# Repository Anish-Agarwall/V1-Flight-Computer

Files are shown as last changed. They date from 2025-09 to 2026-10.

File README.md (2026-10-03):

# V1 Flight Computer

An STM32-based rocket flight computer designed by Anish Agarwal and Aidan Gonzales. This repository contains the KiCad schematics and PCB layout, custom component libraries, and firmware developed in STM32CubeIDE.

The board brings together flight sensing, GPS, LoRa telemetry, microSD logging, main and drogue deployment channels, and a servo output for airbrakes.

## Hardware

The PCB uses four copper layers and an STM32F446RE microcontroller.

| Component | Purpose | Firmware interface |
| --- | --- | --- |
| BMI088 | Accelerometer and gyroscope | I2C1 |
| BMP388 | Pressure, temperature, and barometric altitude | I2C1 |
| LIS3MDL | Magnetometer | I2C1 |
| u-blox NEO-M9N | GPS | USART6 |
| E22-900MM22S | LoRa telemetry | SPI1 |
| W25Q128JVS | 128-Mbit external flash | SPI2 |
| microSD | CSV data logging | SPI3 |

The design also includes battery-voltage and deployment-continuity sensing, a buzzer, a heartbeat LED, and USB-C. The active firmware uses the BMI088; a BMI330 driver is also included in the source tree.

## Firmware

The application is written in C using the STM32 HAL and FatFs. Most of the flight logic is in [`main.c`](V1_STM32/Core/Src/main.c), with separate drivers for the sensors, GPS, radio, SD card, and flash.

The main loop handles:

- Sensor readings and flight-state updates on a nominal 50 ms interval.
- Ground-relative barometric altitude, filtered altitude, and estimated vertical velocity.
- Launch and apogee detection, followed by drogue and main deployment states.
- GPS stream processing and LoRa packet transmission, scheduled at 200 ms intervals.
- Buffered CSV logging to the SD card.
- Servo airbrake control using predicted apogee and a PD controller, enabled seven seconds after launch.

Flight thresholds, deployment settings, and servo limits are defined in `main.c`. The airbrake target and controller gains are inside `Task_Airbrakes()`.

### Data logging

On startup, the firmware selects a numbered log file such as `LOG_0.CSV` or `LOG_1.CSV`. Logged fields include altitude, pressure, temperature, flight state, airbrake output, filtered altitude and velocity, magnetometer readings, and GPS data.

Battery and continuity columns are present, but their periodic sampling task is currently commented out. Data rows also include a Unix timestamp that is missing from the startup CSV header.

The flash driver and a binary logging routine are included, but the current main loop uses the SD logging path and does not call the flash-log flush routine.

## Repository layout

| Path | Contents |
| --- | --- |
| `V1_Hardware/` | KiCad project, schematics, PCB layout, footprints, and 3D models |
| `V1_STM32/` | STM32CubeIDE project and CubeMX configuration |
| `V1_STM32/Core/Src/` | Main application and device drivers |
| `V1_STM32/Core/Inc/` | Headers, telemetry packet definitions, and buffer utilities |
| `V1_STM32/FATFS/` | FatFs configuration and SD disk interface |
| `V1_STM32/Drivers/` | STM32 HAL and CMSIS files |
| `LRA_Parts/` | Component symbols, footprints, and models |

## Opening the project

### Hardware

1. Open `V1_Hardware/V1.kicad_pro` in KiCad. The checked-in design files were saved with KiCad 10.0.
2. In **Preferences → Configure Paths**, set `LRA_PARTS` to the repository's `LRA_Parts` directory.
3. Check the project symbol-library table. Some entries still use absolute Windows paths and need to be pointed to your local copies. Entries that point to a directory should be updated to the corresponding `.kicad_sym` file.

The root schematic is `V1.kicad_sch`. Separate sheets cover power, deployment circuitry, USB-C, memory, GPS/telemetry, and sensors.

### Firmware

1. In STM32CubeIDE, choose **File → Import → General → Existing Projects into Workspace** and select `V1_STM32`.
2. Build the imported project. The repository includes the HAL, CMSIS, and FatFs sources.
3. Use an ST-LINK connection over SWD to program and debug the board. Check the probe settings in the included `V1 Debug.launch` configuration for your setup.

`V1.ioc` contains the CubeMX configuration and records STM32CubeMX 6.14.1 with STM32CubeF4 firmware package V1.28.3. Check the existing application code before regenerating peripheral initialization code.

## Development notes

Some earlier bring-up routines and alternate logging paths remain in the source. Follow the active calls in `main.c` when checking current behavior; a few older comments describe previous pin assignments or hardware revisions.

The `LANDED` state currently follows the main-deployment timer rather than a separate touchdown detector.

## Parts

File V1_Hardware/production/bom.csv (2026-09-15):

Designator | Footprint | Quantity | Value | LCSC Part #
C1, C10, C14, C15, C2, C3, C30, C31, C34, C35, C36, C37, C38, C39, C4, C41, C42, C43, C47, C49, C5, C52, C7, C71, C73, C76 | 0603 | 26 | 100n
C11, C12 | 0603 | 2 | 27p
C13 | 0603 | 1 | 4u7
C17 | 0603 | 1 | 0.47u
C18 | 0805 | 1 | 33u
C28, C40 | 0603 | 2 | 1u
C45, C46, C6, C69, C70, C9 | 0603 | 6 | 10u
C48, C72 | 0603 | 2 | 33n
C50, C51 | 0805 | 2 | 47u
C74, C75 | 0603 | 2 | 22u
C8 | 0603 | 1 | 10n
D1, D2, D4, D7 | 1206 | 4 | RED
J1 | PinHeader_1x04_P2.54mm_Vertical | 1 | Conn_01x04_Pin
J2, J3 | TE_282834-4 | 2 | Screw_Terminal_01x04
J4 | 691210910003 | 1 | Screw_Terminal_01x03
J5, J9 | U.FL_Molex_MCRF_73412-0110_Vertical | 2 | Conn_Coaxial
J7 | 104031-0811 | 1 | 104031-0811
J8 | USB_C_Receptacle_GCT_USB4105-xx-A_16P_TopMnt_Horizontal | 1 | USB_C_Receptacle_USB2.0_16P
L2 | 1210 | 1 | 4.7u
L3 | 1008 | 1 | 27n
L4 | 1008 | 1 | 330n
L6 | 1210 | 1 | 6u8
LS1 | PS1240P02BT | 1 | PS1240P02BT
Q1, Q2 | FDS6681Z | 2 | FDS6681Z
R1, R11, R12, R14, R17, R19, R29, R33, R38, R39, R43, R6, R9 | 0603 | 13 | 10k
R10, R13 | 0603 | 2 | 30k
R15 | 0603 | 1 | 20k
R16 | 0603 | 1 | 2k5
R18, R20 | 0603 | 2 | 100
R2, R30 | 0603 | 2 | 5.1K
R21, R22 | 0603 | 2 | 4k7
R23 | 0603 | 1 | 1k
R25 | 0603 | 1 | 10
R27, R7 | 0603 | 2 | 360k
R28, R8 | 0603 | 2 | 200k
R3, R4 | 0603 | 2 | 75
R34 | 0603 | 1 | 47k
R35 | 0603 | 1 | 15k
R40, R41 | 0603 | 2 | 200
R42 | 0805 | 1 | 90k
R5 | 0603 | 1 | 300
S1, S2 | 500SSP1S1M6QEA | 2 | 500SSP1S1M6QEA
TP1 | TestPoint_Pad_D2.0mm | 1 | 3.3V TestPoint
TP2 | TestPoint_Pad_D2.0mm | 1 | 8V TestPoint
TP3 | TestPoint_Pad_D2.0mm | 1 | VBUS TestPoint
TP4 | TestPoint_Pad_D2.0mm | 1 | GND TestPoint
U1 | LQFP-64_10x10mm_P0.5mm | 1 | STM32F446RETx
U10 | ublox_NEO | 1 | NEO-M9N
U12 | BMP388 | 1 | BMP388
U13, U3 | TPS62933DRLR | 2 | TPS62933DRLR
U15 | LM3940IMPX-3.3_NOPB | 1 | LM3940IMPX-3.3_NOPB
U16 | LGA-12_2x2mm_P0.5mm | 1 | LIS3MDL
U17, U9 | IRLML6346TRPBF | 2 | IRLML6346TRPBF | IRLML6346TRPBF
U2 | SOIC-8_5.3x5.3mm_P1.27mm | 1 | W25Q128JVS
U4 | E22-900MM22S | 1 | E22-900MM22S
U5 | BMI330 | 1 | BMI330
U6 | TPD1E0B04DPYT | 1 | TPD1E0B04DPYT
U7 | TPD4E05U06DQAR | 1 | TPD4E05U06DQAR
Y2 | ABLS-8.000MHZ-B2-T | 1 | ABLS-8.000MHZ-B2-T

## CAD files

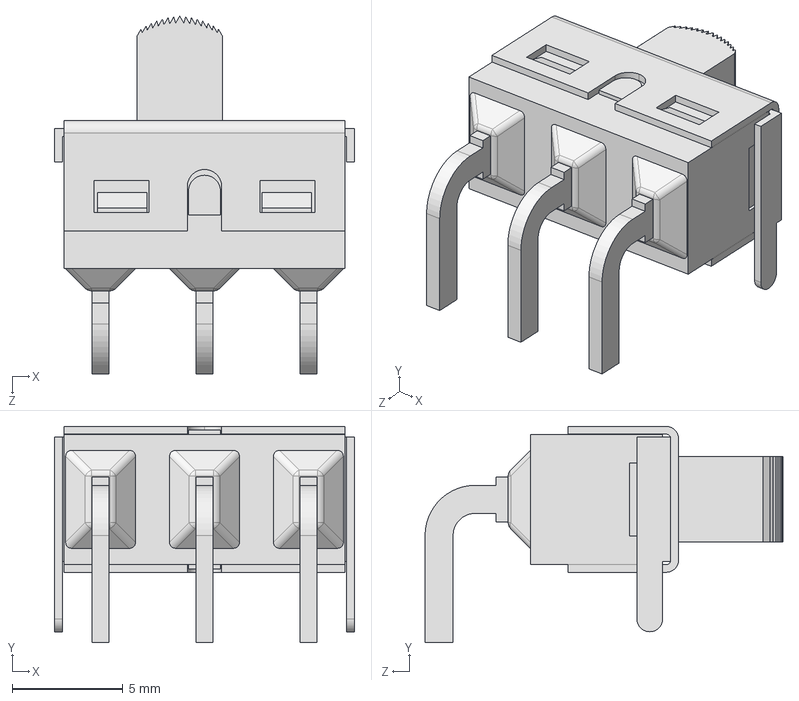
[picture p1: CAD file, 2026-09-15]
LRA_Parts/500SSP1S1M6QEA/500SSP1S1M6QEA.step
13.6 x 9.78 x 16.2 mm

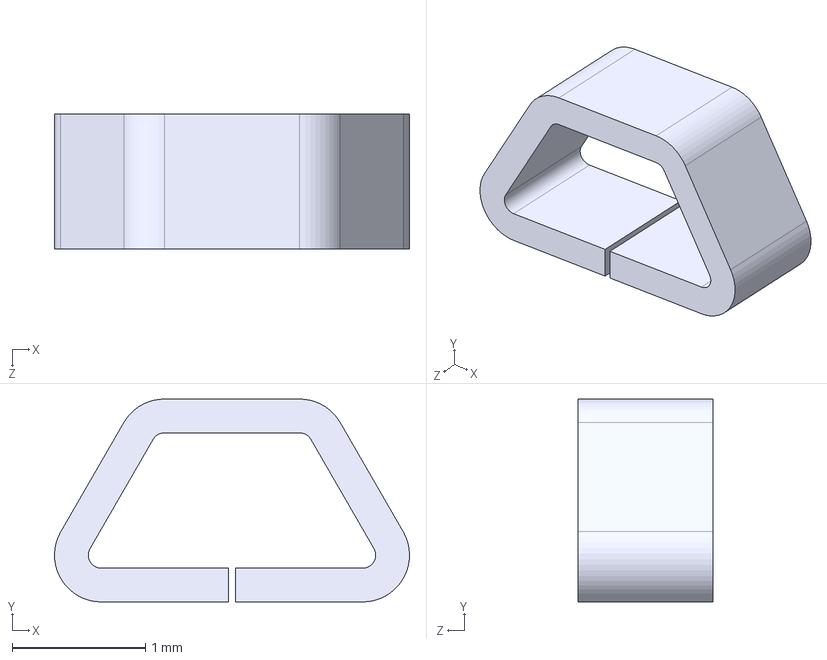
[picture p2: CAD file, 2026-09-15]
LRA_Parts/5015/5015.step
2.67 x 1.52 x 1.02 mm

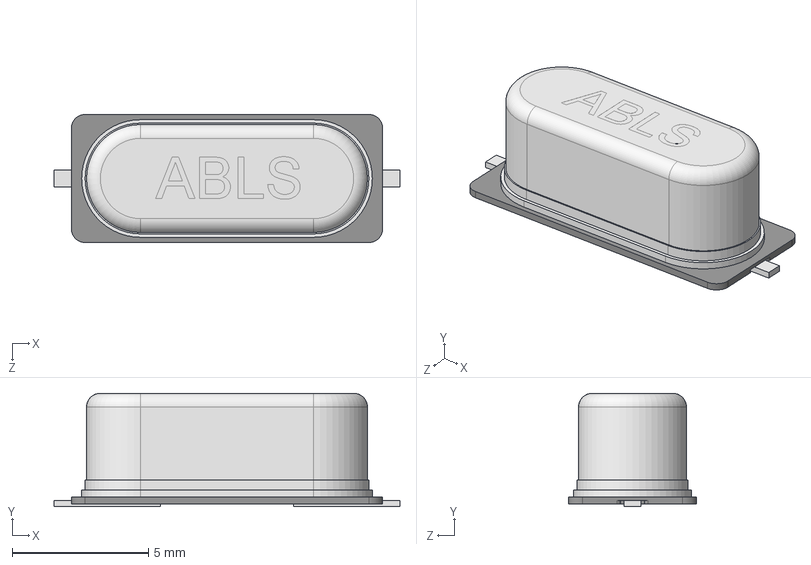
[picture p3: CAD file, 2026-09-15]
LRA_Parts/ABLS-8.000MHZ-B2-T/ABLS-8.000MHZ-B2-T.step
12.7 x 4.17 x 4.70 mm

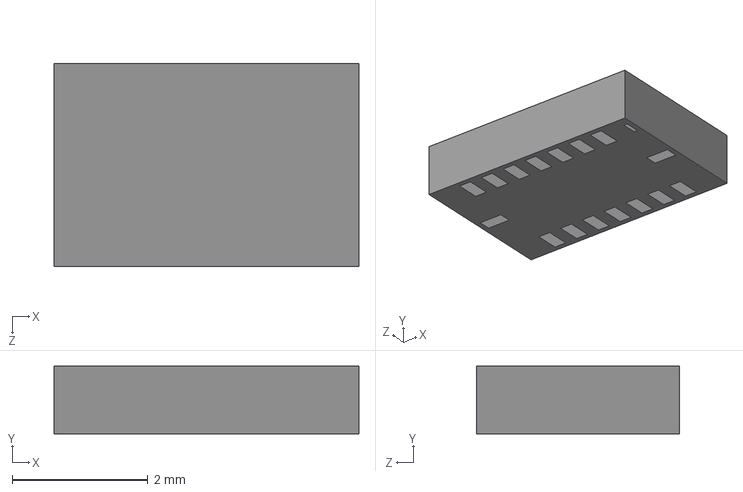
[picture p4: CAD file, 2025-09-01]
LRA_Parts/BMI088/BMI088.step
4.50 x 1.00 x 3.00 mm

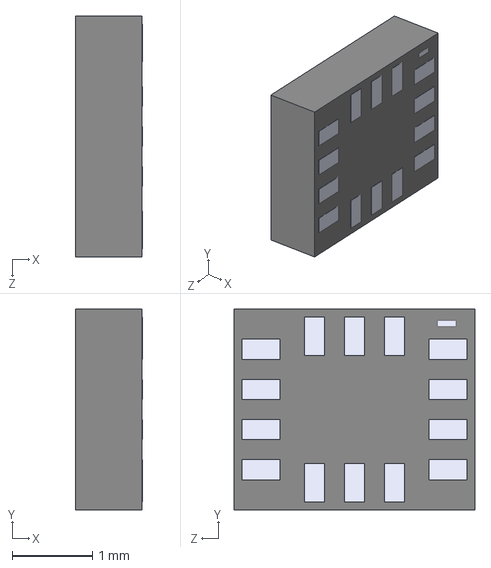
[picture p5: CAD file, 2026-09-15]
LRA_Parts/BMI330/BMI330.stp
0.837 x 2.50 x 3.00 mm

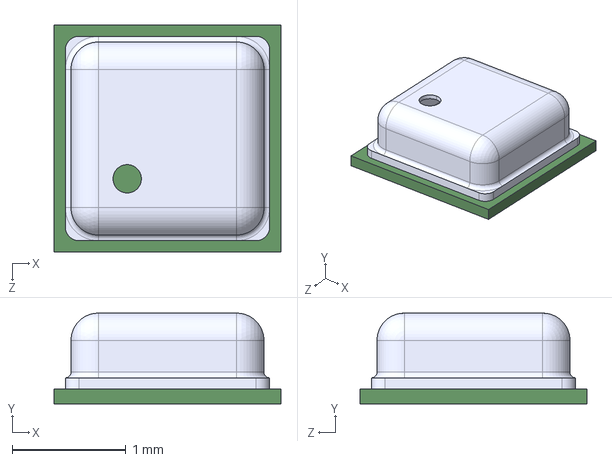
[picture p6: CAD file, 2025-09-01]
LRA_Parts/BMP388/BMP388.step
2.00 x 0.8 x 2.00 mm

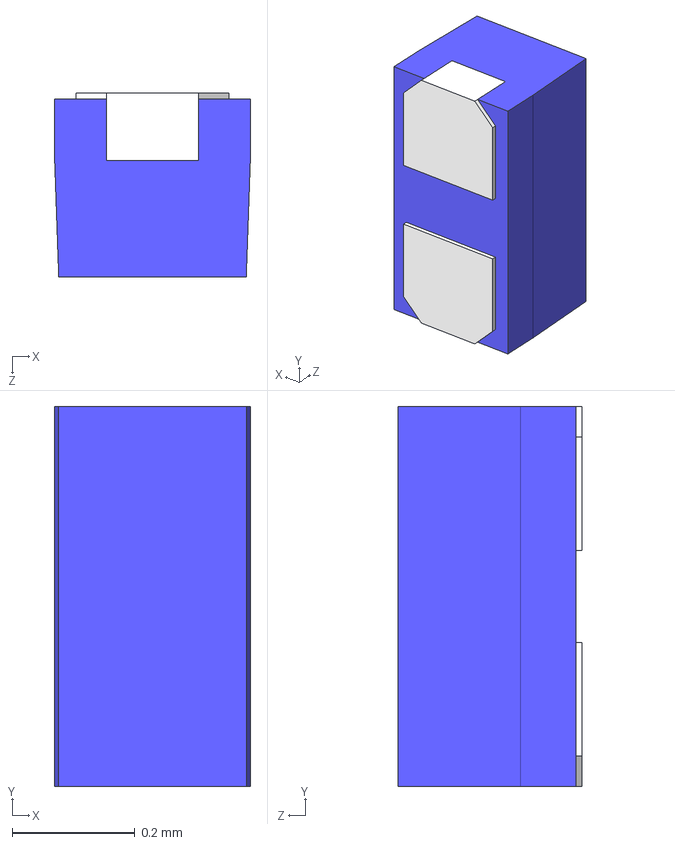
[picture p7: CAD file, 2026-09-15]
LRA_Parts/DF2B6M4SL_L3F/DF2B6M4BSL,L3F.step
0.32 x 0.62 x 0.3 mm

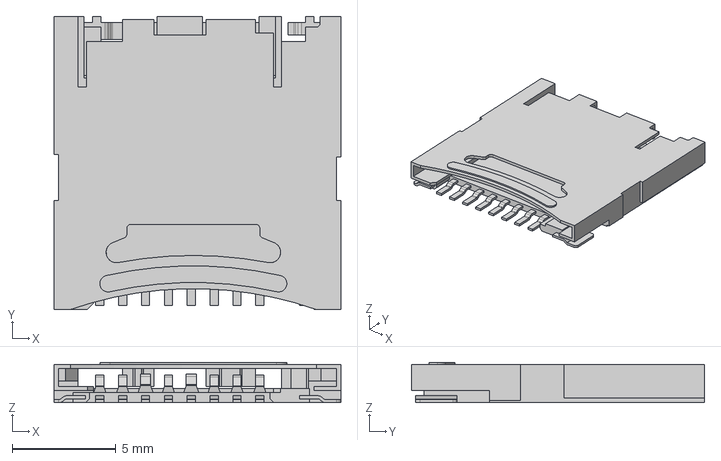
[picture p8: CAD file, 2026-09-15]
LRA_Parts/DM3CS-SF/DM3CS-SF.step
13.8 x 14.1 x 1.93 mm

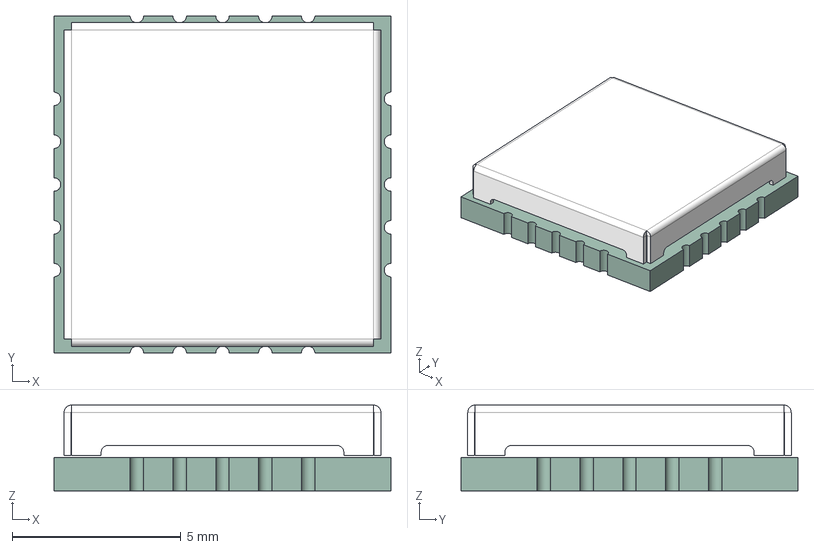
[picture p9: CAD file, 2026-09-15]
LRA_Parts/E22-900MM22S/E07-900MM10S.step
10.0 x 10.0 x 2.55 mm
PBZ-135
10705-V1.1_PCB

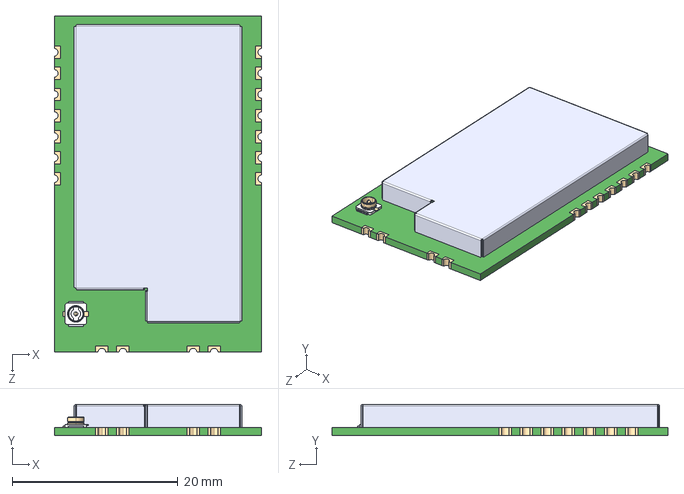
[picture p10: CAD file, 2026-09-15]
LRA_Parts/E22-900T30S/E22-900T30S.step
25.0 x 3.77 x 40.5 mm

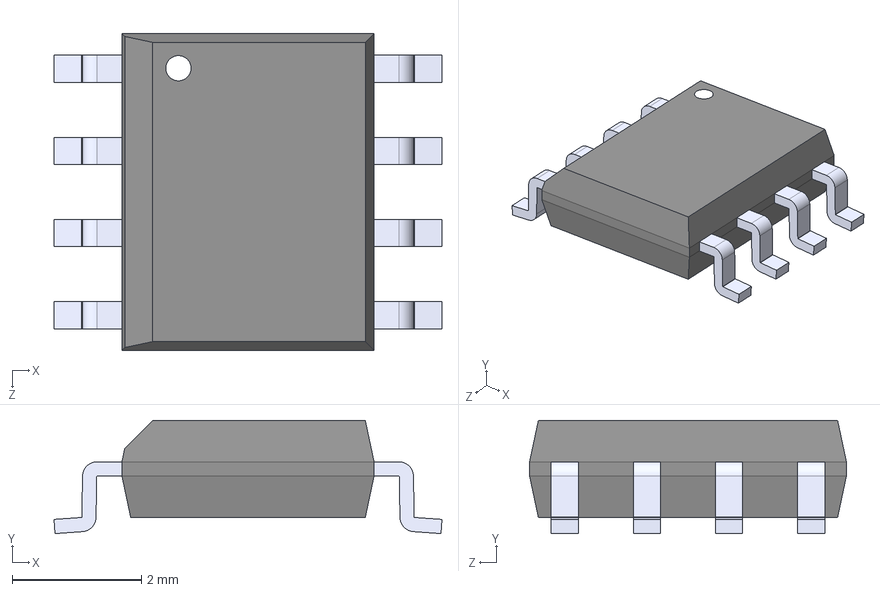
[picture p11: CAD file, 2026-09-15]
LRA_Parts/FDS6681Z/FDS6681Z.step
6.00 x 1.75 x 4.90 mm

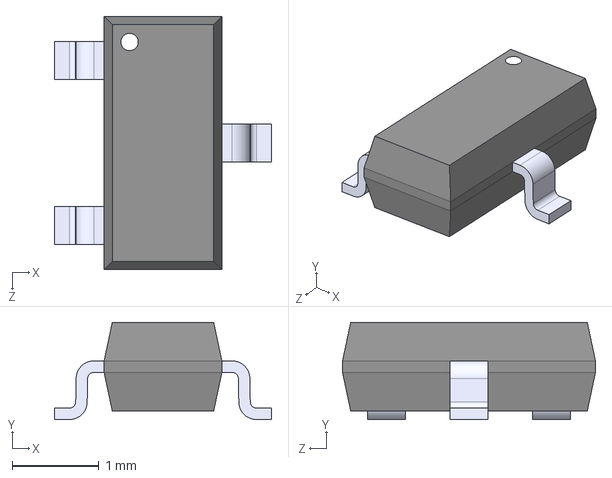
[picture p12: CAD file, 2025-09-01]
LRA_Parts/IRLML6344TRPBF/IRLML6344TRPBF.step
2.51 x 1.12 x 2.92 mm

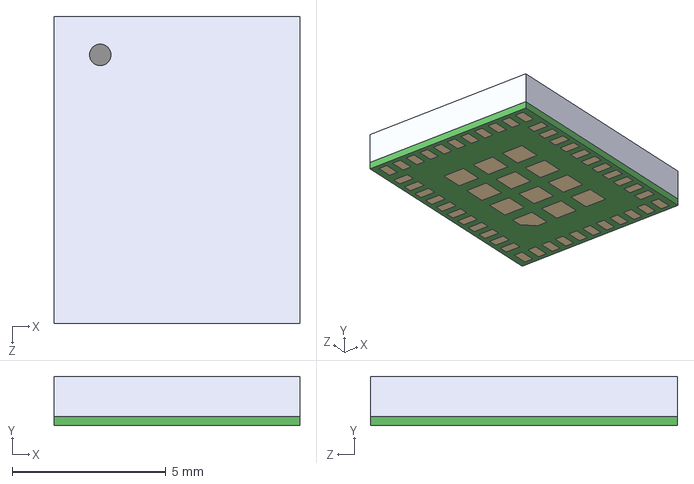
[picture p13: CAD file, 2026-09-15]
LRA_Parts/LBAA0QB1SJ-296/LBAA0QB1SJ-296.step
8.00 x 1.60 x 10.0 mm

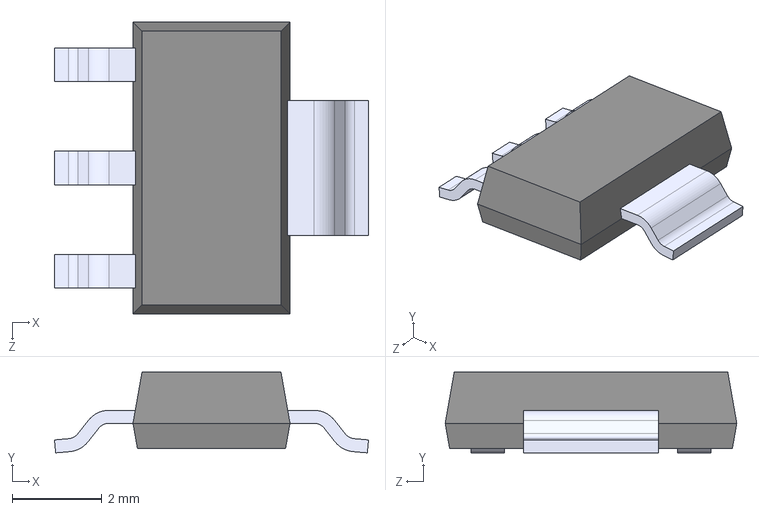
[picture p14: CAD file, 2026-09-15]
LRA_Parts/LM3940IMPX_3_3_NOPB/LM3940IMPX-3.3_NOPB.step
7.00 x 1.80 x 6.50 mm

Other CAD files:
LRA_Parts/IRLML6346TRPBF/IRLML6346TRPBF.step
LRA_Parts/LTST_C171KRKT/LED_LTST-C171_LTO.step
LRA_Parts/NEO-M9N-00B/NEO-M9N-00B.STEP
LRA_Parts/PS1240P02BT/PS1240P02BT.step
LRA_Parts/104031-0811/104031-0811.step
LRA_Parts/282834_4/282834-4.step
LRA_Parts/389690003/389690003.stp
LRA_Parts/389690004/389690004.step
LRA_Parts/691137710003/691137710003.stp
LRA_Parts/691210910003/691210910003.stp
LRA_Parts/TE_282834-4/TE_282834-4.STEP
LRA_Parts/TPD1E0B04DPYT/TPD1E0B04DPYT.step
LRA_Parts/TPD2E001DRSR/TPD2E001DRSR.step
LRA_Parts/TPD2E001DRYR/TPD2E001DRYR.step
LRA_Parts/TPD2E001DZDR/TPD2E001DZDR.step
LRA_Parts/TPD4E05U06DQAR/TPD4E05U06DQAR.step
LRA_Parts/TPS62933DRLR/TPS62933DRLR.step
LRA_Parts/USB4215-03-A_REVA/usb4215-03-a.stp
LRA_Parts/molex_2x1/1053091102.stp
LRA_Parts/molex_3x1/1053091103.stp
LRA_Parts/molex_4x1/1053091104.stp
LRA_Parts/ul_MP2393GTL-Z (1)/SOT583_MP2393.step
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

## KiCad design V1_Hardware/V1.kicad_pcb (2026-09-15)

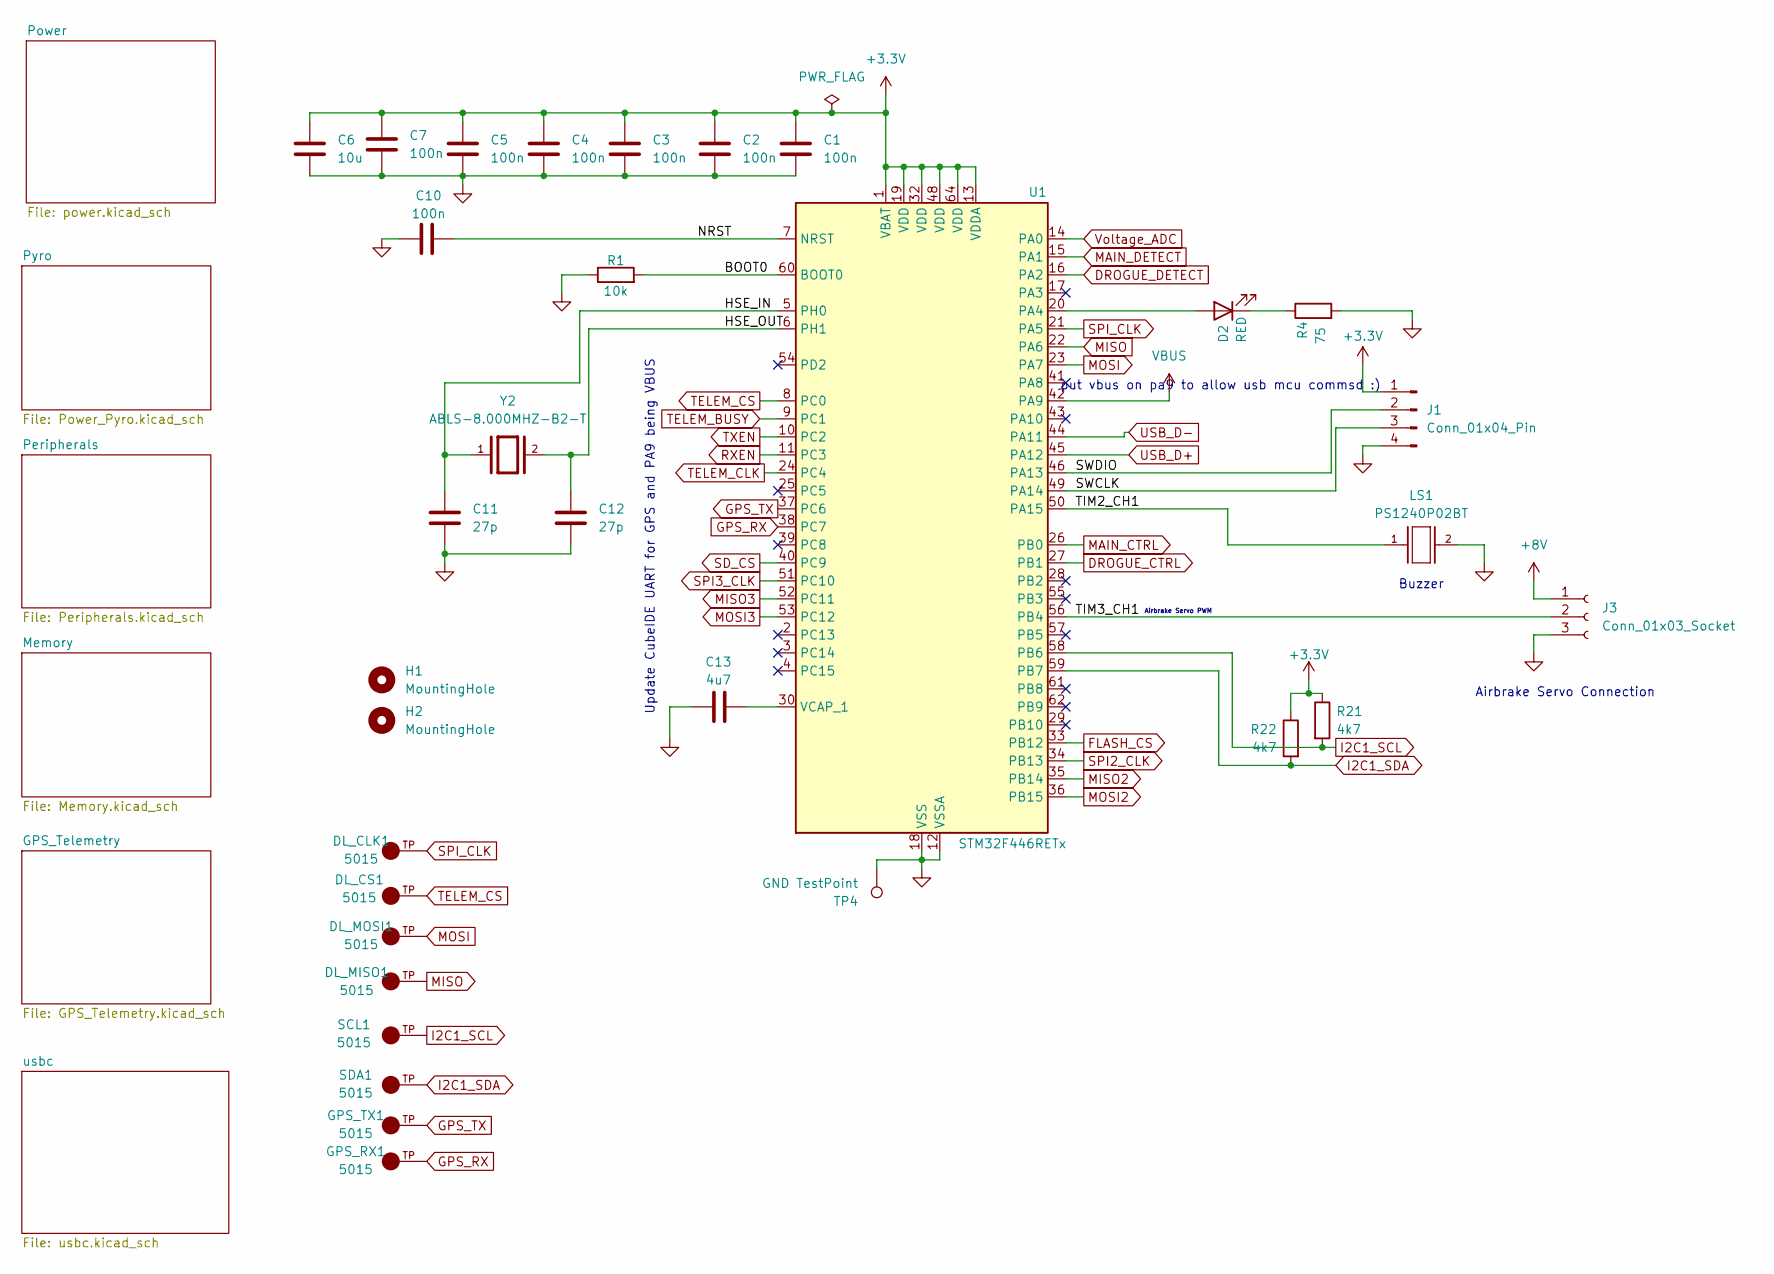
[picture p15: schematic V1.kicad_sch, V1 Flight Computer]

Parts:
C1, C2, C3, C4, C5, C7, C10: 100n; C_0603_1608Metric_Pad1.08x0.95mm_HandSolder
C6: 10u; C_0603_1608Metric_Pad1.08x0.95mm_HandSolder
C11, C12: 27p; C_0603_1608Metric_Pad1.08x0.95mm_HandSolder
C13: 4u7; C_0603_1608Metric_Pad1.08x0.95mm_HandSolder
D2: RED; LED_1206_3216Metric_Pad1.42x1.75mm_HandSolder
DL_CLK1: 5015; PARTREV F
DL_CS1: 5015; PARTREV F
DL_MISO1: 5015; PARTREV F
DL_MOSI1: 5015; PARTREV F
GPS_RX1: 5015; PARTREV F
GPS_TX1: 5015; PARTREV F
H1, H2: MountingHole; MountingHole_3.2mm_M3
J1: Conn_01x04_Pin; PinHeader_1x04_P2.54mm_Vertical
J3: Conn_01x03_Socket; Molex_Nano-Fit_105309-xx03_1x03_P2.50mm_Vertical
LS1: PS1240P02BT
R1: 10k; R_0603_1608Metric_Pad0.98x0.95mm_HandSolder
R4: 75; R_0603_1608Metric_Pad0.98x0.95mm_HandSolder
R21, R22: 4k7; R_0603_1608Metric_Pad0.98x0.95mm_HandSolder
SCL1: 5015; PARTREV F
SDA1: 5015; PARTREV F
TP4: GND TestPoint; TestPoint_Pad_D2.0mm
U1: STM32F446RETx; LQFP-64_10x10mm_P0.5mm
Y2: ABLS-8.000MHZ-B2-T; PARTREV 02.16.2021

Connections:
+3.3V: C1.1, C2.1, C3.1, C4.1, C5.1, C6.1, C7.1, J1.1, R21.1, R22.1, U1.1 (VBAT), U1.13 (VDDA), U1.19 (VDD), U1.32 (VDD), U1.48 (VDD), U1.64 (VDD); also elsewhere on the board
+8V: J3.1; also elsewhere on the board
/BOOT0: R1.2, U1.60 (BOOT0)
/HSE_IN: C11.1, U1.5 (PH0), Y2.1
/HSE_OUT: C12.1, U1.6 (PH1), Y2.2
/NRST: C10.2, U1.7 (NRST)
/SWCLK: J1.3, U1.49 (PA14)
/SWDIO: J1.2, U1.46 (PA13)
/TIM2_CH1: LS1.1, U1.50 (PA15)
/TIM3_CH1: J3.2, U1.56 (PB4)
DROGUE_CTRL: U1.27 (PB1); also elsewhere on the board
DROGUE_DETECT: U1.16 (PA2); also elsewhere on the board
FLASH_CS: U1.33 (PB12); also elsewhere on the board
GND: C1.2, C2.2, C3.2, C4.2, C5.2, C6.2, C7.2, C10.1, C11.2, C12.2, C13.1, J1.4, J3.3, LS1.2, R1.1, R4.2, TP4.1 (1_1), U1.12 (VSSA), U1.18 (VSS), U1.31 (VSS), U1.47 (VSS), U1.63 (VSS); also elsewhere on the board
GPS_RX: GPS_RX1.TP, U1.38 (PC7); also elsewhere on the board
GPS_TX: GPS_TX1.TP, U1.37 (PC6); also elsewhere on the board
I2C1_SCL: R21.2, SCL1.TP, U1.58 (PB6); also elsewhere on the board
I2C1_SDA: R22.2, SDA1.TP, U1.59 (PB7); also elsewhere on the board
MAIN_CTRL: U1.26 (PB0); also elsewhere on the board
MAIN_DETECT: U1.15 (PA1); also elsewhere on the board
MISO: DL_MISO1.TP, U1.22 (PA6); also elsewhere on the board
MISO2: U1.35 (PB14); also elsewhere on the board
MISO3: U1.52 (PC11); also elsewhere on the board
MOSI: DL_MOSI1.TP, U1.23 (PA7); also elsewhere on the board
MOSI2: U1.36 (PB15); also elsewhere on the board
MOSI3: U1.53 (PC12); also elsewhere on the board
unnamed: D2.2 (A), U1.20 (PA4)
unnamed: D2.1 (K), R4.1
unnamed: C13.2, U1.30 (VCAP_1)
RXEN: U1.11 (PC3); also elsewhere on the board
SD_CS: U1.40 (PC9); also elsewhere on the board
SPI2_CLK: U1.34 (PB13); also elsewhere on the board
SPI3_CLK: U1.51 (PC10); also elsewhere on the board
SPI_CLK: DL_CLK1.TP, U1.21 (PA5); also elsewhere on the board
TELEM_BUSY: U1.9 (PC1); also elsewhere on the board
TELEM_CLK: U1.24 (PC4); also elsewhere on the board
TELEM_CS: DL_CS1.TP, U1.8 (PC0); also elsewhere on the board
TXEN: U1.10 (PC2); also elsewhere on the board
USB_D+: U1.45 (PA12); also elsewhere on the board
USB_D-: U1.44 (PA11); also elsewhere on the board
VBUS: U1.42 (PA9); also elsewhere on the board
Voltage_ADC: U1.14 (PA0); also elsewhere on the board

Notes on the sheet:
Update CubeIDE UART for GPS and PA9 being VBUS
put vbus on pa9 to allow usb mcu commsd :)
Airbrake Servo Connection
Airbrake Servo PWM
Buzzer

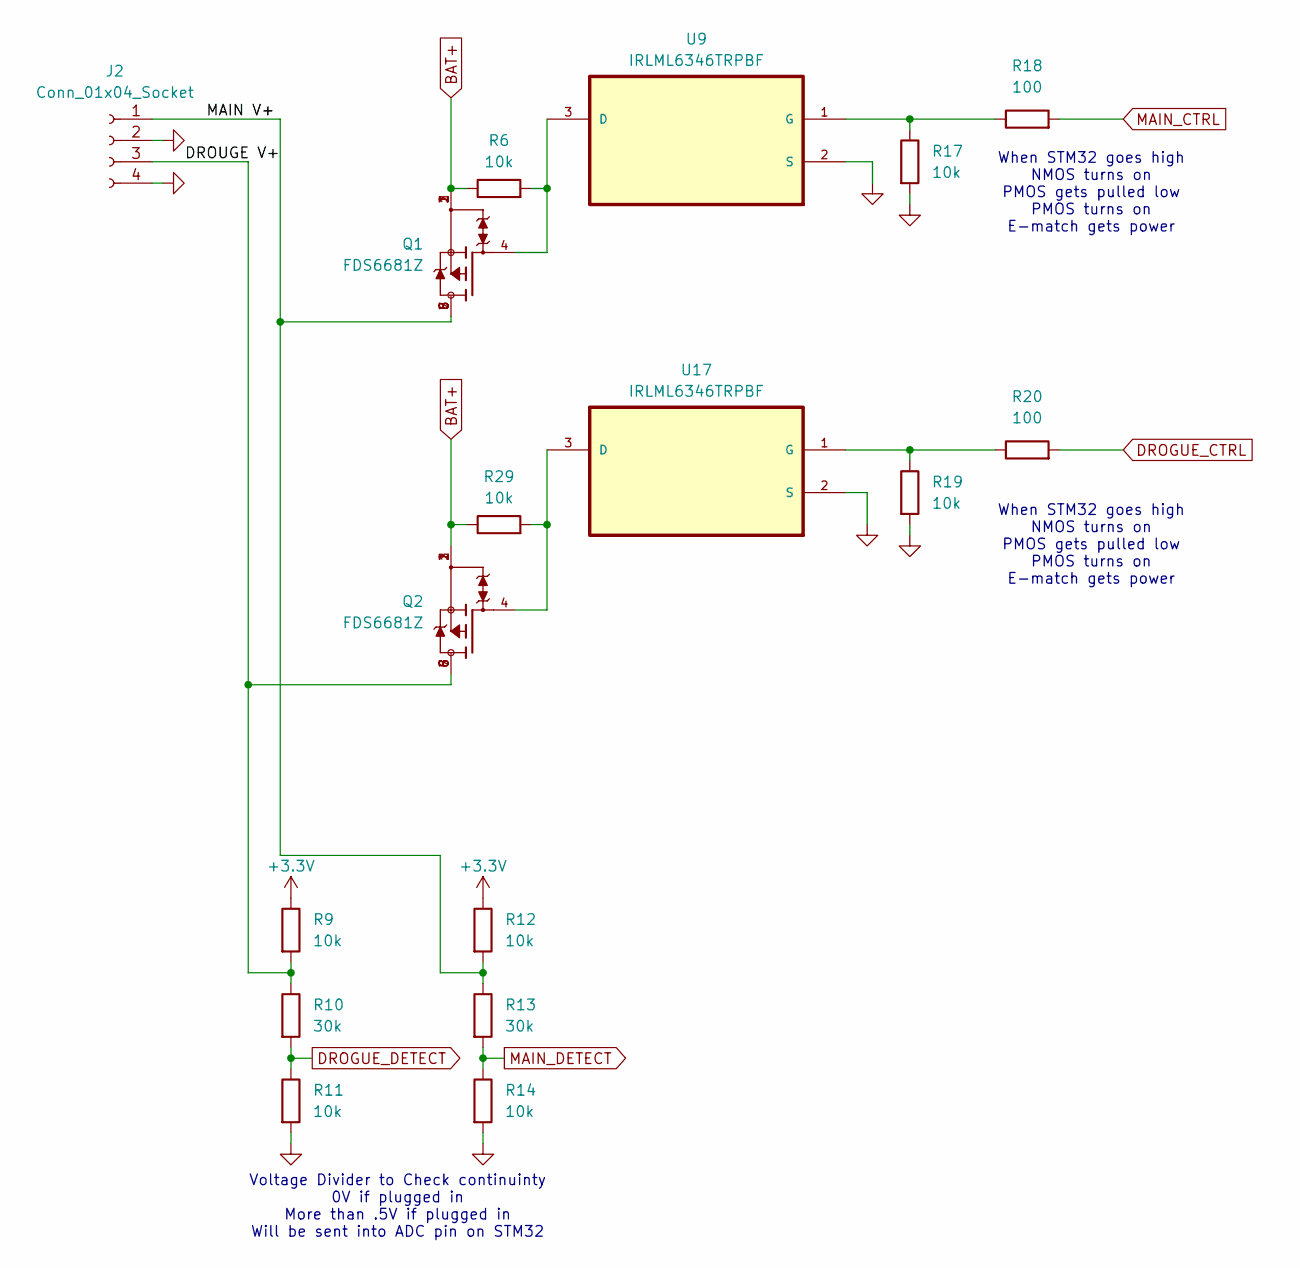
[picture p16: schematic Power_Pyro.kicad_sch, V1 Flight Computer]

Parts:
J2: Conn_01x04_Socket; Molex_Nano-Fit_105309-xx04_1x04_P2.50mm_Vertical
Q1, Q2: FDS6681Z
R6, R9, R11, R12, R14, R17, R19, R29: 10k; R_0603_1608Metric_Pad0.98x0.95mm_HandSolder
R10, R13: 30k; R_0603_1608Metric_Pad0.98x0.95mm_HandSolder
R18, R20: 100; R_0603_1608Metric_Pad0.98x0.95mm_HandSolder
U9, U17: IRLML6346TRPBF; MPN IRLML6346TRPBF

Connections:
+3.3V: R9.1, R12.1; also elsewhere on the board
/Pyro/DROUGE V+: J2.3, Q2.5, Q2.6, Q2.7, Q2.8, R9.2, R10.1
/Pyro/MAIN V+: J2.1, Q1.5, Q1.6, Q1.7, Q1.8, R12.2, R13.1
BAT+: Q1.1, Q1.2, Q1.3, Q2.1, Q2.2, Q2.3, R6.1, R29.1; also elsewhere on the board
DROGUE_CTRL: R20.2; also elsewhere on the board
DROGUE_DETECT: R10.2, R11.1; also elsewhere on the board
GND: J2.2, J2.4, R11.2, R14.2, R17.2, R19.2, U9.2 (S), U17.2 (S); also elsewhere on the board
MAIN_CTRL: R18.2; also elsewhere on the board
MAIN_DETECT: R13.2, R14.1; also elsewhere on the board
unnamed: Q1.4, R6.2, U9.3 (D)
unnamed: R17.1, R18.1, U9.1 (G)
unnamed: Q2.4, R29.2, U17.3 (D)
unnamed: R19.1, R20.1, U17.1 (G)

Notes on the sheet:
Voltage Divider to Check continuinty 0V if plugged in More than .5V if plugged in Will be sent into ADC pin on STM32
When STM32 goes high NMOS turns on PMOS gets pulled low PMOS turns on E-match gets power

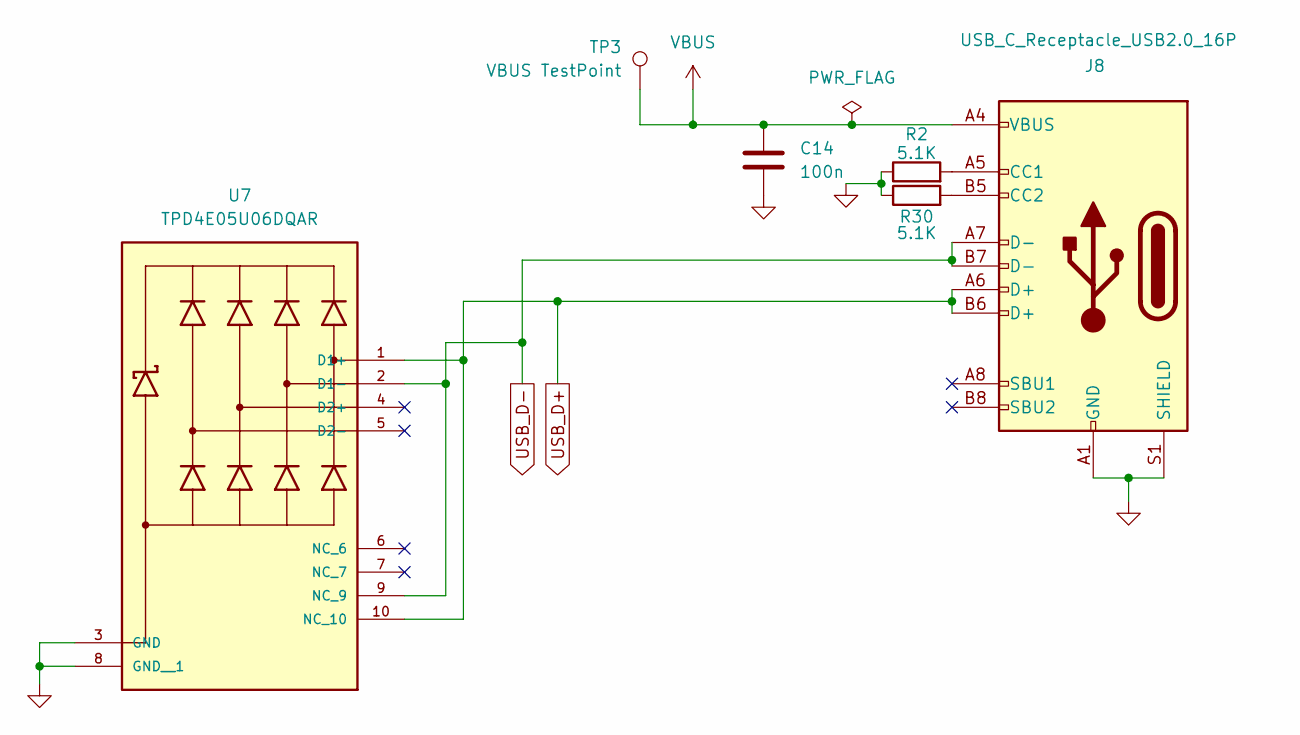
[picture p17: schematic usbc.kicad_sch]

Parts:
C14: 100n; C_0603_1608Metric_Pad1.08x0.95mm_HandSolder
J8: USB_C_Receptacle_USB2.0_16P; USB_C_Receptacle_GCT_USB4105-xx-A_16P_TopMnt_Horizontal
R2, R30: 5.1K; R_0603_1608Metric_Pad0.98x0.95mm_HandSolder
TP3: VBUS TestPoint; TestPoint_Pad_D2.0mm
U7: TPD4E05U06DQAR; PARTREV N

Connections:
GND: C14.1, J8.A1 (GND), J8.A12 (GND), J8.B1 (GND), J8.B12 (GND), J8.S1 (SHIELD), R2.1, R30.1, U7.3 (GND), U7.8 (GND__1); also elsewhere on the board
unnamed: J8.A5 (CC1), R2.2
unnamed: J8.B5 (CC2), R30.2
USB_D+: J8.A6 (D+), J8.B6 (D+), U7.1 (D1+), U7.10 (NC_10); also elsewhere on the board
USB_D-: J8.A7 (D-), J8.B7 (D-), U7.2 (D1-), U7.9 (NC_9); also elsewhere on the board
VBUS: C14.2, J8.A4 (VBUS), J8.A9 (VBUS), J8.B4 (VBUS), J8.B9 (VBUS), TP3.1 (1_1); also elsewhere on the board

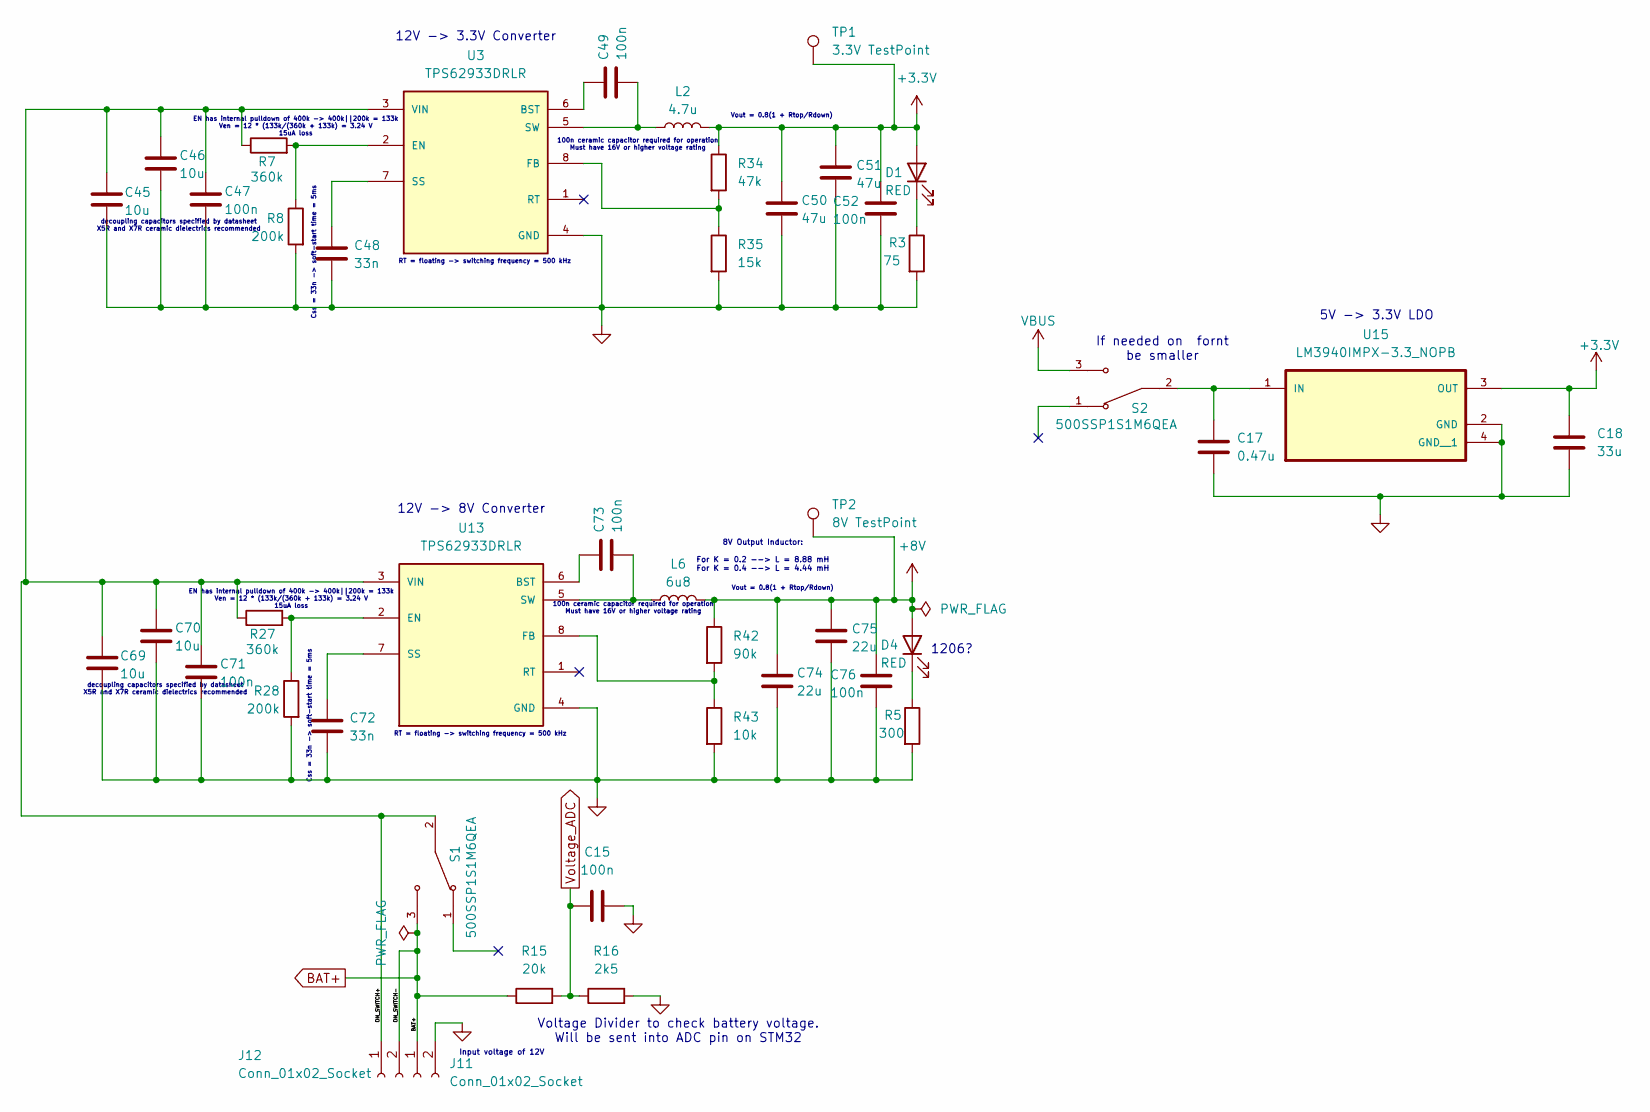
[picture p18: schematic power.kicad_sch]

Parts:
C15, C47, C49, C52, C71, C73, C76: 100n; C_0603_1608Metric_Pad1.08x0.95mm_HandSolder
C17: 0.47u; C_0603_1608Metric_Pad1.08x0.95mm_HandSolder
C18: 33u; C_0805_2012Metric_Pad1.18x1.45mm_HandSolder
C45, C46, C69, C70: 10u; C_0603_1608Metric_Pad1.08x0.95mm_HandSolder
C48, C72: 33n; C_0603_1608Metric_Pad1.08x0.95mm_HandSolder
C50, C51: 47u; C_0805_2012Metric_Pad1.18x1.45mm_HandSolder
C74, C75: 22u; C_0603_1608Metric_Pad1.08x0.95mm_HandSolder
D1, D4: RED; LED_1206_3216Metric_Pad1.42x1.75mm_HandSolder
J11, J12: Conn_01x02_Socket; Molex_Nano-Fit_105309-xx02_1x02_P2.50mm_Vertical
L2: 4.7u; L_1210_3225Metric_Pad1.42x2.65mm_HandSolder
L6: 6u8; L_1210_3225Metric_Pad1.42x2.65mm_HandSolder
R3: 75; R_0603_1608Metric_Pad0.98x0.95mm_HandSolder
R5: 300; R_0603_1608Metric_Pad0.98x0.95mm_HandSolder
R7, R27: 360k; R_0603_1608Metric_Pad0.98x0.95mm_HandSolder
R8, R28: 200k; R_0603_1608Metric_Pad0.98x0.95mm_HandSolder
R15: 20k; R_0603_1608Metric_Pad0.98x0.95mm_HandSolder
R16: 2k5; R_0603_1608Metric_Pad0.98x0.95mm_HandSolder
R34: 47k; R_0603_1608Metric_Pad0.98x0.95mm_HandSolder
R35: 15k; R_0603_1608Metric_Pad0.98x0.95mm_HandSolder
R42: 90k; R_0805_2012Metric_Pad1.20x1.40mm_HandSolder
R43: 10k; R_0603_1608Metric_Pad0.98x0.95mm_HandSolder
S1, S2: 500SSP1S1M6QEA; PARTREV D
TP1: 3.3V TestPoint; TestPoint_Pad_D2.0mm
TP2: 8V TestPoint; TestPoint_Pad_D2.0mm
U3, U13: TPS62933DRLR; PARTREV D
U15: LM3940IMPX-3.3_NOPB

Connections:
+3.3V: C18.1, C50.1, C51.1, C52.1, D1.2 (A), L2.2, R34.1, TP1.1 (1_1), U15.3 (OUT); also elsewhere on the board
+8V: C74.1, C75.1, C76.1, D4.2 (A), L6.2, R42.1, TP2.1 (1_1); also elsewhere on the board
/Power/ON_SWITCH+: C45.1, C46.1, C47.1, C69.1, C70.1, C71.1, J12.1, R7.1, R27.1, S1.2, U3.3 (VIN), U13.3 (VIN)
BAT+: J11.1, J12.2, R15.1, S1.3; also elsewhere on the board
GND: C15.2, C17.2, C18.2, C45.2, C46.2, C47.2, C48.2, C50.2, C51.2, C52.2, C69.2, C70.2, C71.2, C72.2, C74.2, C75.2, C76.2, J11.2, R3.2, R5.2, R8.2, R16.2, R28.2, R35.2, R43.2, U3.4 (GND), U13.4 (GND), U15.2 (GND), U15.4 (GND__1); also elsewhere on the board
unnamed: D1.1 (K), R3.1
unnamed: D4.1 (K), R5.1
unnamed: C49.1, U3.6 (BST)
unnamed: R7.2, R8.1, U3.2 (EN)
unnamed: R34.2, R35.1, U3.8 (FB)
unnamed: C48.1, U3.7 (SS)
unnamed: C49.2, L2.1, U3.5 (SW)
unnamed: C73.1, U13.6 (BST)
unnamed: R27.2, R28.1, U13.2 (EN)
unnamed: R42.2, R43.1, U13.8 (FB)
unnamed: C72.1, U13.7 (SS)
unnamed: C73.2, L6.1, U13.5 (SW)
unnamed: C17.1, S2.2, U15.1 (IN)
VBUS: S2.3; also elsewhere on the board
Voltage_ADC: C15.1, R15.2, R16.1; also elsewhere on the board

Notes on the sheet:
8V Output Inductor: For K = 0.2 --> L = 8.88 mH For K = 0.4 --> L = 4.44 mH
12V -> 8V Converter
Vout = 0.8(1 + Rtop/Rdown)
Voltage Divider to check battery voltage. Will be sent into ADC pin on STM32
100n ceramic capacitor required for operation Must have 16V or higher voltage rating
Css = 33n -> soft-start time = 5ms
EN has internal pulldown of 400k -> 400k||200k = 133k Ven = 12 * (133k/(360k + 133k) = 3.24 V 15uA loss
RT = floating -> switching frequency = 500 kHz
5V -> 3.3V LDO
Input voltage of 12V
1206?
12V -> 3.3V Converter
decoupling capacitors specified by datasheet X5R and X7R ceramic dielectrics recommended
If needed on fornt be smaller

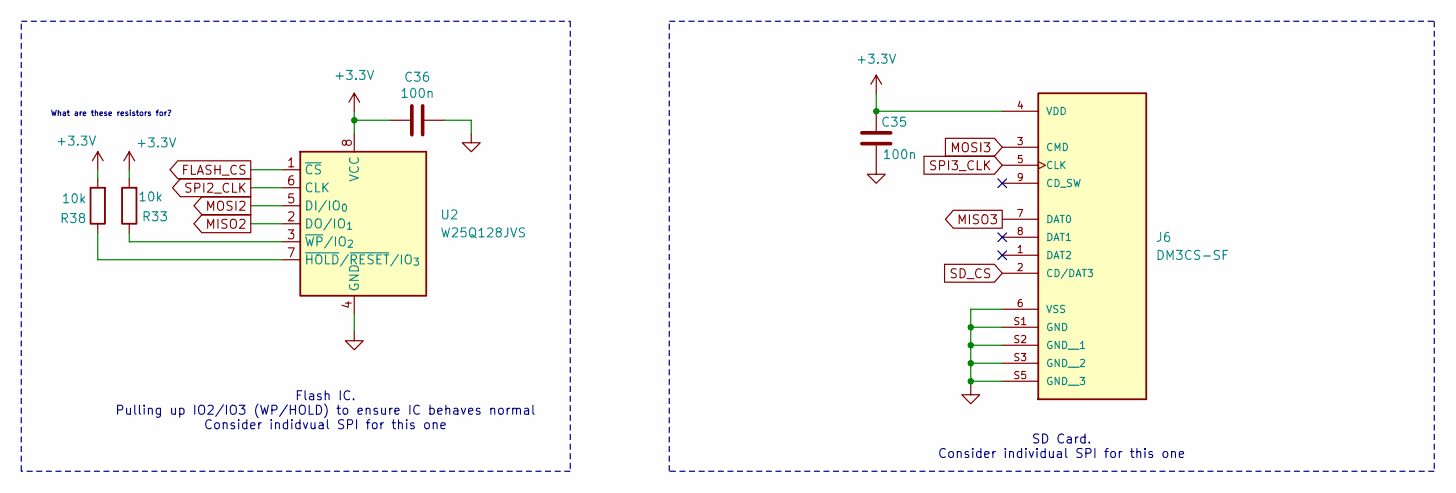
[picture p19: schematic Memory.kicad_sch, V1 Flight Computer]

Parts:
C35, C36: 100n; C_0603_1608Metric_Pad1.08x0.95mm_HandSolder
J6: DM3CS-SF; PARTREV n/a
R33, R38: 10k; R_0603_1608Metric_Pad0.98x0.95mm_HandSolder
U2: W25Q128JVS; SOIC-8_5.3x5.3mm_P1.27mm

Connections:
+3.3V: C35.2, C36.1, J6.4 (VDD), R33.2, R38.2, U2.8 (VCC); also elsewhere on the board
FLASH_CS: U2.1 (~CS); also elsewhere on the board
GND: C35.1, C36.2, J6.6 (VSS), J6.S1 (GND), J6.S2 (GND__1), J6.S3 (GND__2), J6.S5 (GND__3), U2.4 (GND); also elsewhere on the board
MISO2: U2.2 (DO/IO_{1}); also elsewhere on the board
MISO3: J6.7 (DAT0); also elsewhere on the board
MOSI2: U2.5 (DI/IO_{0}); also elsewhere on the board
MOSI3: J6.3 (CMD); also elsewhere on the board
unnamed: R38.1, U2.7 (~HOLD/~RESET/IO_{3})
unnamed: R33.1, U2.3 (~WP/IO_{2})
SD_CS: J6.2 (CD/DAT3); also elsewhere on the board
SPI2_CLK: U2.6 (CLK); also elsewhere on the board
SPI3_CLK: J6.5 (CLK); also elsewhere on the board

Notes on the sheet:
Flash IC. Pulling up IO2/IO3 (WP/HOLD) to ensure IC behaves normal Consider indidvual SPI for this one
SD Card. Consider individual SPI for this one
What are these resistors for?

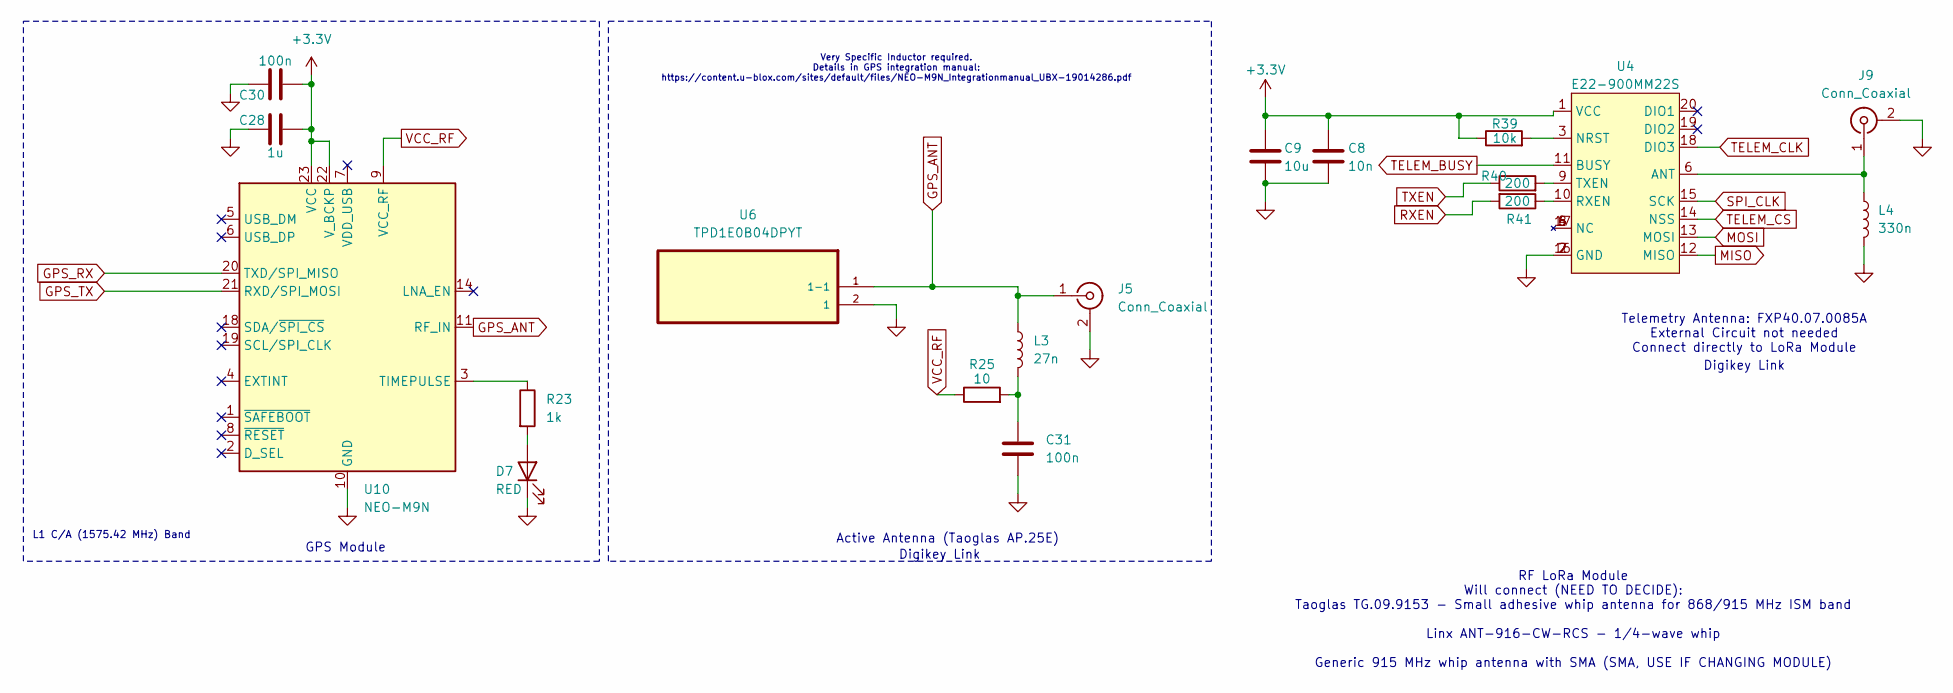
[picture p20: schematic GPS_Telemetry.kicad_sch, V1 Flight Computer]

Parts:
C8: 10n; C_0603_1608Metric_Pad1.08x0.95mm_HandSolder
C9: 10u; C_0603_1608Metric_Pad1.08x0.95mm_HandSolder
C28: 1u; C_0603_1608Metric_Pad1.08x0.95mm_HandSolder
C30, C31: 100n; C_0603_1608Metric_Pad1.08x0.95mm_HandSolder
D7: RED; LED_1206_3216Metric_Pad1.42x1.75mm_HandSolder
J5, J9: Conn_Coaxial; U.FL_Molex_MCRF_73412-0110_Vertical
L3: 27n; L_1008_2520Metric_Pad1.43x2.20mm_HandSolder
L4: 330n; L_1008_2520Metric_Pad1.43x2.20mm_HandSolder
R23: 1k; R_0603_1608Metric_Pad0.98x0.95mm_HandSolder
R25: 10; R_0603_1608Metric_Pad0.98x0.95mm_HandSolder
R39: 10k; R_0603_1608Metric_Pad0.98x0.95mm_HandSolder
R40, R41: 200; R_0603_1608Metric_Pad0.98x0.95mm_HandSolder
U4: E22-900MM22S
U6: TPD1E0B04DPYT
U10: NEO-M9N; ublox_NEO

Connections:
+3.3V: C8.1, C9.1, C28.2, C30.2, R39.1, U4.1 (VCC), U10.22 (V_BCKP), U10.23 (VCC); also elsewhere on the board
GND: C8.2, C9.2, C28.1, C30.1, C31.2, D7.1 (K), J5.2 (Ext), J9.2 (Ext), L4.2, U4.2 (GND), U4.7 (GND), U4.16 (GND), U6.2 (1), U10.10 (GND), U10.12 (GND), U10.13 (GND), U10.24 (GND); also elsewhere on the board
GPS_ANT: J5.1 (In), L3.1, U6.1 (1-1), U10.11 (RF_IN)
GPS_RX: U10.20 (TXD/SPI_MISO); also elsewhere on the board
GPS_TX: U10.21 (RXD/SPI_MOSI); also elsewhere on the board
MISO: U4.12 (MISO); also elsewhere on the board
MOSI: U4.13 (MOSI); also elsewhere on the board
unnamed: C31.1, L3.2, R25.2
unnamed: D7.2 (A), R23.2
unnamed: J9.1 (In), L4.1, U4.6 (ANT)
unnamed: R39.2, U4.3 (NRST)
unnamed: R41.1, U4.10 (RXEN)
unnamed: R40.2, U4.9 (TXEN)
unnamed: R23.1, U10.3 (TIMEPULSE)
RXEN: R41.2; also elsewhere on the board
SPI_CLK: U4.15 (SCK); also elsewhere on the board
TELEM_BUSY: U4.11 (BUSY); also elsewhere on the board
TELEM_CLK: U4.18 (DIO3); also elsewhere on the board
TELEM_CS: U4.14 (NSS); also elsewhere on the board
TXEN: R40.1; also elsewhere on the board
VCC_RF: R25.1, U10.9 (VCC_RF)

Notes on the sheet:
RF LoRa Module Will connect (NEED TO DECIDE): Taoglas TG.09.9153 - Small adhesive whip antenna for 868/915 MHz ISM band Linx ANT-916-CW-RCS - 1/4-wave whip Generic 915 MHz whip antenna with SMA (SMA, USE IF CHANGING MODULE)
Active Antenna (Taoglas AP.25E)
L1 C/A (1575.42 MHz) Band
Digikey Link
GPS Module
Very Specific Inductor required. Details in GPS integration manual: https://content.u-blox.com/sites/default/files/NEO-M9N_Integrationmanual_UBX-19014286.pdf
Telemetry Antenna: FXP40.07.0085A External Circuit not needed Connect directly to LoRa Module

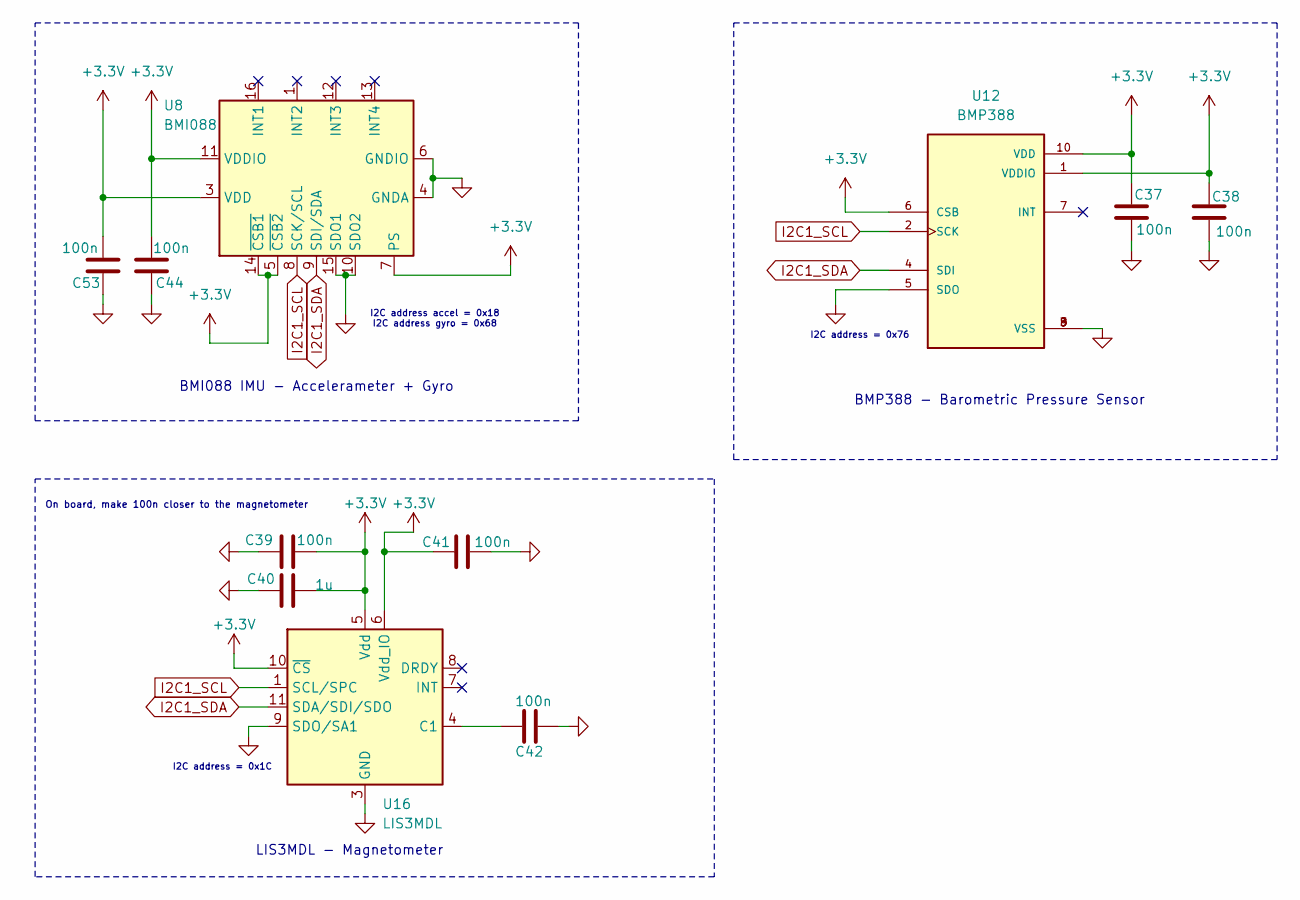
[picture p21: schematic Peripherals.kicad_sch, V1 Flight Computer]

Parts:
C37, C38, C39, C41, C42, C44, C53: 100n; C_0603_1608Metric_Pad1.08x0.95mm_HandSolder
C40: 1u; C_0603_1608Metric_Pad1.08x0.95mm_HandSolder
U8: BMI088; Bosch_LGA-16_4.5x3mm_P0.5mm_LayoutBorder7x1y_ClockwisePinNu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
U12: BMP388; PARTREV 1.1
U16: LIS3MDL; LGA-12_2x2mm_P0.5mm

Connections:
+3.3V: C37.1, C38.1, C39.2, C40.2, C41.2, C44.2, C53.2, U8.3 (VDD), U8.5 (~CSB2), U8.7 (PS), U8.11 (VDDIO), U8.14 (~CSB1), U12.1 (VDDIO), U12.6 (CSB), U12.10 (VDD), U16.5 (Vdd), U16.6 (Vdd_IO), U16.10 (~CS); also elsewhere on the board
GND: C37.2, C38.2, C39.1, C40.1, C41.1, C42.1, C44.1, C53.1, U8.2 (GNDA), U8.4 (GNDA), U8.6 (GNDIO), U8.10 (SDO2), U8.15 (SDO1), U12.3 (VSS), U12.5 (SDO), U12.8 (VSS), U12.9 (VSS), U16.2 (GND), U16.3 (GND), U16.9 (SDO/SA1), U16.12 (GND); also elsewhere on the board
I2C1_SCL: U8.8 (SCK/SCL), U12.2 (SCK), U16.1 (SCL/SPC); also elsewhere on the board
I2C1_SDA: U8.9 (SDI/SDA), U12.4 (SDI), U16.11 (SDA/SDI/SDO); also elsewhere on the board
unnamed: C42.2, U16.4 (C1)

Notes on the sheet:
LIS3MDL - Magnetometer
I2C address = 0x76
I2C address = 0x1C
I2C address accel = 0x18 I2C address gyro = 0x68
BMI088 IMU - Accelerameter + Gyro
BMP388 - Barometric Pressure Sensor
On board, make 100n closer to the magnetometer

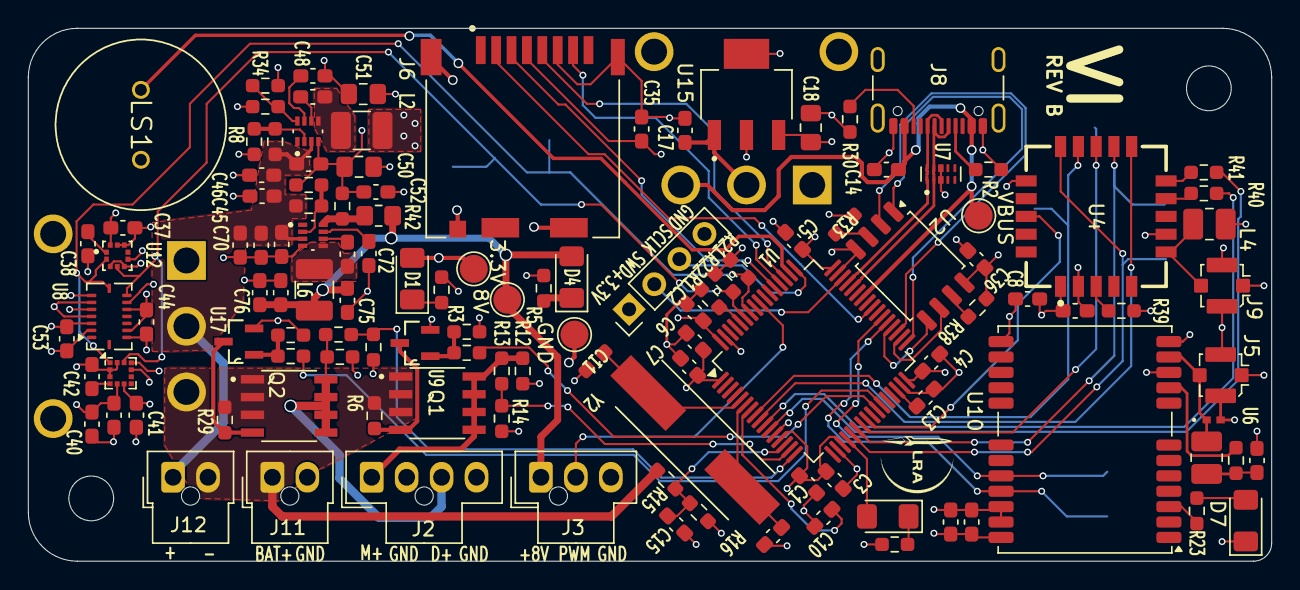
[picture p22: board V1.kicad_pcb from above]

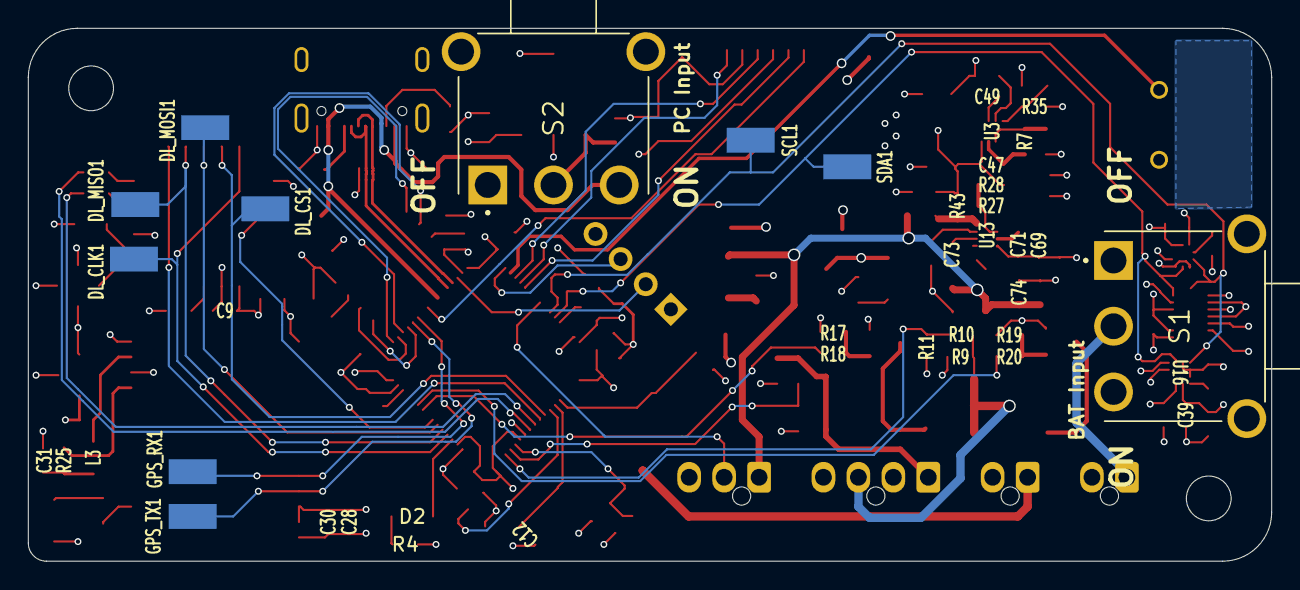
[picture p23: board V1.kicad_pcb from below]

Board: 4 copper layers, 88.9 x 38.1 mm, 134 parts (10 on the bottom side), 77 nets.

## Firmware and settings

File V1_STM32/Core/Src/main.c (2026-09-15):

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
/* Includes ------------------------------------------------------------------*/
#include "main.h"
#include "fatfs.h"

/* USER CODE BEGIN Includes */

#include <stdio.h>
#include <string.h>
#include <stdlib.h>
#include <math.h>
#include <stdint.h>

#include "circular_buffer.h"

#include "bmi088.h"
#include "bmp388.h"
#include "lis3mdl.h"
#include "NEO-M9N.h"
#include "w25q128jvs.h"
#include "1040310811.h"
#include "E22_900MM22S.h"







/* USER CODE END Includes */

/* USER CODE BEGIN PD */


// PINS
#define HEARTBEAT_Pin GPIO_PIN_4
#define HEARTBEAT_GPIO_Port GPIOA
#define MAIN_FIRE_Pin GPIO_PIN_0
#define MAIN_FIRE_GPIO_Port GPIOB
#define DROGUE_FIRE_Pin GPIO_PIN_1
#define DROGUE_FIRE_GPIO_Port GPIOB

// BUZZER (PA15)
#define BUZZER_PERIOD 999
#define BUZZER_DUTY 500 // half


#define AIRBRAKE_TIM_PRESCALER 71
#define AIRBRAKE_TIM_PERIOD 19999
#define AIRBRAKE_RETRACTED_US 500 // pulse width in microseconds // was 1000
#define AIRBRAKE_DEPLOYED_US 2000 // was 2706


//#define AIRBRAKE_DEPLOY_ALT_M 300.0f
#define AIRBRAKE_DEPLOY_ALT_M 1679.1f

static float curr_deployment_level = 0.0f;


// 1500 ft AGL = 457.2 m
// main fires on descent below this only after drogie
#define MAIN_DEPLOY_ALT_M 457.2f




// SD BUFFER DEFINES
#define SD_WRITE_BUFFER_SIZE 512
char sd_text_buffer[SD_WRITE_BUFFER_SIZE];
uint16_t buffer_index = 0;



Packet_t telemetry_pkt;



// LOOP MININGS in MS
#define IMU_UPDATE 10
#define BARO_UPDATE 50
#define CONTINUITY_UPDATE_MS 5000
#define HEARTBEAT_UPDATE 500
#define TELEMETRY_UPDATE 200


// how often we write the FIFO buffers to sd and clagsh
#define _FLUSH_MS 500

// ADC for battery
#define ADC_VREF_MV 3300
#define ADC_MAX_COUNTS 4095
// 20k top / 2.5k bottom
// scale = (20 + 2.5) / 2.5 = 9
#define VDIV_SCALE 9.0f
// Continuity Check
#define CONTINUITY_OPEN_MV 400



// sd stuff (double check this)
#define SD_LOG_START_SECTOR 2048u
#define CSV_LINE_BUF 320


// AI, DOUBLE CHECK THIS TO MAKE SURE IT MAKES SENSE
// Flash logging — raw binary record (20 bytes each)
// layout: uint32 time_ms | float alt | float pressure | float temp | float bat_v | uint8 stage | 3-byte pad
#define FLASH_RECORD_SIZE   32u
#define FLASH_MAX_ADDR      0xFFFFFF    // 16 MB (W25Q128)



// default flight config

// launch detection
// 100 ft
#define DEF_LAUNCH_ALT_M 30.48f
// min 2g
#define DEF_LAUNCH_G_M 2.0f

// deployment altitude (lowkey dont use lol, just here to essentially hard start it)
// both are disabled for now, but just here for testing down the road
#define DEF_MAIN_ALT_M 0.0f
#define DEF_DROGUE_ALT_M 0.0f

// pyro channel
// currently set to 5 seconds, change later on.
#define DEF_MAIN_FIRE_MS 5000
#define DEF_DROGUE_FIRE_MS 2000

// hard set timers (use for testing)
#define DEF_MAIN_TIMER_MS 0
#define DEF_DROGUE_TIMER_MS 0

// apogee settins
// do not fire main a apogee, fire only drogue
#define DEF_MAIN_ON_APOGEE 0
#define DEF_DROGUE_ON_APOGEE 1

// if altitude has dropped this many meters below the max, here, we reachd apogee
#define APOGEE_DROP_M           10.0f

// used in loop to see how many samples to confirm dropping
#define APOGEE_CONFIRM_SAMPLES  5


/* USER CODE END PD */

ADC_HandleTypeDef hadc1;

I2C_HandleTypeDef hi2c1;

SPI_HandleTypeDef hspi1;
SPI_HandleTypeDef hspi2;
SPI_HandleTypeDef hspi3;

TIM_HandleTypeDef htim2;
TIM_HandleTypeDef htim3;

UART_HandleTypeDef huart1;
UART_HandleTypeDef huart6;

PCD_HandleTypeDef hpcd_USB_OTG_FS;

/* USER CODE BEGIN PV */



FATFS fs;
FIL logFile;
uint8_t sd_mounted = 0;




// Sensors
BMI088_Data_t imu;
BMP388_Calib_t baro;
LIS3MDL_Data_t mag;

// live sensor data values
// g
float ax = 0;
float ay = 0;
float az = 0;
// deg/s
float gx = 0;
float gy = 0;
float gz = 0;
// pa
float pressure = 0;
// celcisu
float temperature = 0;
// m
float altitude = 0;

// ADC detect
// mv
// 0 = connected & 500 = open
uint16_t main_detect = 0;
uint16_t drogue_detect = 0;
// 12V rail check
float bat_voltage = 0;


// ****************************************************** PUT GPS STUFF HER

extern NEO_M9N_Data_t gps_data;





// hard set info
// all definitions above, not typoing this again lol
float cfg_launch_alt_m = DEF_LAUNCH_ALT_M;
float cfg_launch_g_m = DEF_LAUNCH_G_M;

float cfg_main_alt_m = DEF_MAIN_ALT_M;
float cfg_drogue_alt_m = DEF_DROGUE_ALT_M;

int32_t cfg_main_fire_ms = DEF_MAIN_FIRE_MS;
int32_t cfg_drogue_fire_ms = DEF_DROGUE_FIRE_MS;

int32_t cfg_main_timer_ms = DEF_MAIN_TIMER_MS;
int32_t cfg_drogue_timer_ms= DEF_DROGUE_TIMER_MS;

uint8_t cfg_main_on_apogee = DEF_MAIN_ON_APOGEE;
uint8_t cfg_drogue_on_apogee = DEF_DROGUE_ON_APOGEE;

// flight state
FlightStage_t stage = NOT_LAUNCHED;
uint32_t launch_time_ms = 0;
uint32_t main_fired_ms = 0;
uint32_t drogue_fired_ms = 0;
float ground_alt_abs = 0.0;	// absolute baro altitude at pad
float peak_alt_agl = 0.0f; // highest AGL seen so far


// airbrake state flag
static uint8_t airbrake_deployed = 0;
static uint8_t activate_airbrakes = 0;



// circ bif
// going to be used for state detection
CircBuf_t  recent_alt;


// fifo buffers
// log time
LogU32Buf_t log_time;

LogU32Buf_t log_servo;
LogFloatBuf_t log_airbrakes_level;
LogFloatBuf_t log_filtered_alt;
LogFloatBuf_t log_filtered_vel;

// pressure, temp, altitude (bmp)
LogFloatBuf_t log_pres;
LogFloatBuf_t log_temp;
LogFloatBuf_t log_alt;

// g's on 3 axis (bmi)
LogFloatBuf_t log_ax;
LogFloatBuf_t log_ay;
LogFloatBuf_t log_az;

// deg/s on 3 axis (bmi)
LogFloatBuf_t log_gx;
LogFloatBuf_t log_gy;
LogFloatBuf_t log_gz;

// voltage detection
LogFloatBuf_t log_main_mv;
LogFloatBuf_t log_drogue_mv;
LogFloatBuf_t log_bat_v;

// mag
LogFloatBuf_t mag_x_buf;
LogFloatBuf_t mag_y_buf;
LogFloatBuf_t mag_z_buf;
LogFloatBuf_t mag_temp_buf;

// gps
//LogU32Buf_t gps_year;
//LogU32Buf_t gps_month;
//LogU32Buf_t gps_day;
//LogU32Buf_t gps_hour;
//LogU32Buf_t gps_min;
//LogU32Buf_t gps_sec;
LogFloatBuf_t gps_longitude;
LogFloatBuf_t gps_latitude;
LogFloatBuf_t gps_speed;
LogFloatBuf_t gps_heading_deg;

// imu
LogFloatBuf_t imu_acc_x;
LogFloatBuf_t imu_acc_y;
LogFloatBuf_t imu_acc_z;

LogFloatBuf_t imu_gyro_x;
LogFloatBuf_t imu_gyro_y;
LogFloatBuf_t imu_gyro_z;




// stage
LogStageBuf_t log_stage;

// timestamp
LogU32Buf_t log_unix;

// sd stuff (double check this)
static uint32_t sd_sector = SD_LOG_START_SECTOR;
static uint8_t  sd_available = 0;
static uint8_t  sd_buf[512];
static uint16_t sd_buf_pos = 0;

// flash pointer (double check this)
static uint32_t flash_addr = 0x000000;
static uint8_t  flash_available = 0;


// timing travkers for the loop
static uint32_t t_imu = 0;
static uint32_t t_baro = 0;
static uint32_t t_cont = 0;
static uint32_t t_hb = 0;
static uint32_t t_flush = 0;
static uint32_t t_telem = 0;


static int pre_log_ctr = 0;




/* USER CODE END PV */

void SystemClock_Config(void);
static void MX_GPIO_Init(void);
static void MX_ADC1_Init(void);
static void MX_SPI1_Init(void);
static void MX_SPI2_Init(void);
static void MX_SPI3_Init(void);

static void MX_SPI3_Init_Fast(void);

static void MX_USART1_UART_Init(void);
static void MX_USB_OTG_FS_PCD_Init(void);
static void MX_TIM2_Init(void);
static void MX_TIM3_Init(void);
static void MX_I2C1_Init(void);
static void MX_USART6_UART_Init(void);
/* USER CODE BEGIN PFP */

// bring up code
void Bringup_I2C(void);
void Bringup_SPI_Flash(void);
void Bringup_SPI_SD(void);
void Bringup_SPI_DL(void);
void Bringup_UART_GPS(void);


// init
static void Init_Sensors(void);
static void Init_SD(void);

static void Init_Buffers(void);

static void Init_Flash(void);

// config stuff
static void Load_Config(void);
static void Parse_Config_Line(const char *line);



// adc for main and drogue node reads
static uint16_t ADC_Read_mV(uint32_t channel);

// buzzer
static void Buzzer_On(void);
static void Buzzer_Off(void);
static void Buzzer_Beep(uint32_t ms);


// airbreka helpers
static void Airbrake_Retract(void);
static void Airbrake_Deploy(void);

// Pyro helpers
static void Fire_Drogue(void);
static void Fire_Main(void);
static void Pyro_Safe(void);




// loop task funcs
static void Task_IMU(void);
static void Task_Baro(void);
//static void Task_Mag(void);
static void Task_Continuity(void);
static void Task_Heartbeat(void);
static void Task_GPS(void);
static void Task_Telemetry(void);
static void Task_FlightState(void);
static void Task_Pyro(void);
static void Task_PyroChecks(void);
static void Task_Logging(void);
static void Task_LogFlush(void);
static void Task_SD_Write(void);
static void Task_Airbrakes(void);


// sd/flash helpers
static void SD_Flush(void);
static void Flash_Write_Record_Raw(uint32_t ts, float alt, float prs, float tmp, float bv, uint8_t st);


// telem
static void Telem_Send(void);



// math funcs (mayber)
static float Altitude_From_Pressure(float pa);



// misc (idk)


// altitude and velocity filtering
uint8_t filter_init = 0;
float filtered_alt = 0;
float filtered_vel = 0;
const float alt_alpha = 0.5;
const float vel_alpha = 0.85;

uint32_t now;









BYTE work[4096];


// drogue and main fired flags
int drogue_fired_flag = 0;
int main_fired_flag = 0;




/* USER CODE END PFP */

/**
  * @brief  The application entry point.
  * @retval int
  */
int main(void)
{

  /* USER CODE BEGIN 1 */

	char log_buffer[100];
	UINT byteswritten;




  /* USER CODE END 1 */

  /* MCU Configuration--------------------------------------------------------*/

  /* Reset of all peripherals, Initializes the Flash interface and the Systick. */
  HAL_Init();

  /* Configure the system clock */
  SystemClock_Config();

  /* Initialize all configured peripherals */
  MX_GPIO_Init();
  MX_ADC1_Init();
  MX_SPI1_Init();
  MX_SPI2_Init();
  MX_SPI3_Init();
  MX_USART1_UART_Init();
  MX_USB_OTG_FS_PCD_Init();
  MX_TIM2_Init();
  MX_TIM3_Init();
  MX_I2C1_Init();
  MX_FATFS_Init();
  MX_USART6_UART_Init();
  /* USER CODE BEGIN 2 */

  HAL_Delay(100);


//  FRESULT res;
//  res = f_mount(&fs, "", 1);
//
//  // Initialize FatFS and Mount SD Card
//  if (f_mount(&fs, "", 1) == FR_OK) {
//      // Try to open/create the file.
//      // If FA_OPEN_APPEND gives an error, use (FA_OPEN_ALWAYS | FA_WRITE)
//      if (f_open(&logFile, "LOG.CSV", FA_OPEN_APPEND | FA_WRITE | FA_CREATE_ALWAYS) == FR_OK) {
//          sd_mounted = 1;
//          // Write CSV Header
//          f_printf(&logFile, "Time_ms,Alt_m,Pres_Pa,Temp_C,Bat_V,Stage\n");
//          f_sync(&logFile); // Force write to card
//      }
//  }

  HAL_Delay(1000);  // let card power rail settle

  __HAL_TIM_SET_AUTORELOAD(&htim3, AIRBRAKE_TIM_PERIOD);
  __HAL_TIM_SET_COMPARE(&htim3, TIM_CHANNEL_1, AIRBRAKE_RETRACTED_US);
  htim3.Instance->EGR = TIM_EGR_UG;
  HAL_TIM_PWM_Start(&htim3, TIM_CHANNEL_1);


  extern FATFS USERFatFS;
  extern char USERPath[4];
  FRESULT res;

  res = f_mount(&USERFatFS, USERPath, 1);
  MX_SPI3_Init_Fast();


  if (res == FR_NO_FILESYSTEM) {
      // Card has no FAT — format it (only happens once on a blank card)
      //BYTE work[4096];
	  //     JUST CHANGED THE FM_FAT32 TO THE ORRED VERSION
      res = f_mkfs(USERPath, FM_FAT32 | FM_SFD, 0, work, sizeof(work));
      if (res == FR_OK) {
          f_mount(NULL, USERPath, 0);
          res = f_mount(&USERFatFS, USERPath, 1);
      }
  }

  if (res == FR_OK) {
	  //FRESULT temporary = f_open(&logFile, "0:LOG.CSV",
      //        FA_OPEN_APPEND | FA_WRITE | FA_CREATE_ALWAYS);

	  char filename[16];
	  int file_idx = 0;
	  FRESULT res_stat;
	  FILINFO fno;

	  do {
		  sprintf(filename, "0:LOG_%d.CSV", file_idx++);
		  res_stat = f_stat(filename, &fno);
	  } while (res_stat == FR_OK && file_idx < 1000);


      FRESULT temporary = f_open(&logFile, filename, FA_CREATE_ALWAYS | FA_WRITE);



      if (temporary == FR_OK) {
          //f_lseek(&logFile, f_size(&logFile));
          sd_available = 1;
          sd_mounted   = 1;
          const char *header = "Time_ms,Alt_m,Pres_Pa,Temp_C,Bat_V,Main_mV,Drogue_mV,Stage,Servo,Airbrakes_Level,Filtered_Alt,Filtered_Vel,Mag_x,Mag_y,Mag_z,Mag_temp,"
        		  "GPS_longitude,GPS_latitude,GPS_speed,GPS_heading_deg\r\n";
          UINT bytes_written = 0;
          //temporary = f_printf(&logFile,
          //    "Time_ms,Alt_m,Pres_Pa,Temp_C,Bat_V,Main_mV,Drogue_mV,Stage\r\n");
          //temporary = f_sync(&logFile);

          temporary = f_write(&logFile, header, strlen(header), &bytes_written);

          // temporary = f_close(&logFile);

          f_sync(&logFile);


      }
  }



//	if (res == FR_OK) {
//		if (f_open(&logFile, "LOG.CSV", FA_OPEN_ALWAYS | FA_WRITE) == FR_OK) {
//			f_lseek(&logFile, f_size(&logFile));  // append to end
//			sd_mounted = 1;
//			sd_available = 1;
//			f_printf(&logFile, "Time_ms,Alt_m,Pres_Pa,Temp_C,Bat_V,Stage\n");
//			f_sync(&logFile);
//		}
//	}




  // pyro and airbrakes off
  Pyro_Safe();
  Airbrake_Retract();


  // init bufgf
  Init_Buffers();

  // init sensors
  Init_Sensors();

  // init sd and flahs
  //Init_SD();
  Init_Flash();




  // bmp needs to wait until it chills out ngl
  HAL_Delay(500);
  BMP388_ReadData(&hi2c1, &baro);
  ground_alt_abs = baro.altitude;

  // ready beeps, 3 short beeps for all good
  for (int i = 0; i < 3; i++) {
	  Buzzer_Beep(80);
	  HAL_Delay(80);
  }

  HAL_TIM_PWM_Start(&htim3, TIM_CHANNEL_1);


  static uint16_t sync_counter = 0; // Initialize counter outside the loop if not using 'static'

// airbrake testing code
//  while (1) {
//	  Airbrake_Deploy();
//	  HAL_Delay(5000);
//	  Airbrake_Retract();
//	  HAL_Delay(5000);
//  }

  /* USER CODE END 2 */

  /* Infinite loop */
  /* USER CODE BEGIN WHILE */
  while (1)
  {
    /* USER CODE END WHILE */


//
//	sprintf(log_buffer, "%lu, %.2f, %.2f\r\n", HAL_GetTick(), altitude, pressure);
//
//	if (f_write(&logFile, log_buffer, strlen(log_buffer), &byteswritten) == FR_OK)
//	{
//		f_sync(&logFile);
//		sync_counter++;
//	}
//
//	HAL_Delay(10);

	// BOARD BRING UP CODE
//	Bringup_I2C();
	//	Bringup_SPI_Flash();
	//Bringup_SPI_SD();
//		Bringup_SPI_DL();
//	Bringup_UART_GPS();
	//	HAL_Delay(500);
	//
	//
	//	Init_Sensors();
	//	HAL_GPIO_TogglePin(HEARTBEAT_GPIO_Port, HEARTBEAT_Pin);
	//
	//	Task_Baro();



	now = HAL_GetTick();

	// servo PWM test
//	while (1) {
//		Airbrake_Deploy();
//		HAL_Delay(1000);
//		Airbrake_Retract();
//		HAL_Delay(1000);
//	}

	Task_GPS(); // It needs to be called frequently so the rx buffer doesn't get full, but maybe move this



	if ((drogue_fired_flag) && ((now - drogue_fired_ms) > 1000)) {
		HAL_GPIO_WritePin(DROGUE_FIRE_GPIO_Port, DROGUE_FIRE_Pin, GPIO_PIN_RESET);
		drogue_fired_flag = 0;
	}

	if ((main_fired_flag) && ((now - main_fired_ms) > 1000)) {
		HAL_GPIO_WritePin(MAIN_FIRE_GPIO_Port, MAIN_FIRE_Pin, GPIO_PIN_RESET);
		main_fired_flag = 0;
	}


	// flight stuff
	if ((now - t_baro) >= BARO_UPDATE) {
		t_baro = now;
		Task_Baro();
		Task_IMU();
		Task_FlightState();
		Task_Pyro();
		Task_Logging();				// MOVE DATA RETRIEVAL AND LOGGING TO AN INTERRUPT, AND DO SD WRITES IN MAIN WHILE LOOP


	}

	// FIXME: I removed this because we aren't connecting charges
//	// contuintuy check
//	if ((now - t_cont) >= CONTINUITY_UPDATE_MS) {
//		t_cont = now;
//		Task_Continuity();
//	}

	// heartbeat
	if ((now - t_hb) >= HEARTBEAT_UPDATE) {
		t_hb = now;
		Task_Heartbeat();
	}

	// FIXME
	// using t_telem, TELEMETRY_UPDATE, and Task_Telemetry() that Anish defined
//	if ((now - t_telem) >= TELEMETRY_UPDATE) {
//		t_telem = now;
//		Task_Telemetry();
//	}

	Task_Telemetry();


	Task_SD_Write();


	if (stage == LANDED && sd_mounted) {
		//Task_LogFlush();
		Task_SD_Write();

		f_close(&logFile);

		sd_mounted = 0;
	}

	if ((stage == LAUNCHED) && ((now - launch_time_ms) >= 7000)) {
		activate_airbrakes = 1;
	}





  }
  /* USER CODE END 3 */
}

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
/* USER CODE BEGIN 4 */



// BOARD BRING UP CODE
void Bringup_I2C(){

	int BMI088Aaddress = 0x18; // 0x18
	int BMI088Gaddress = 0x68; // 0x68

//	int BMI330address = 0x68;
	int LS3MDLaddress = 0x1C;
	int BMP388address = 0x76;

	int BMI088DummyReg = 0x00;
//	int BMI330DummyReg = 0x00;
	int LS3MDLDummyReg = 0x0F;
	int BMP388DummyReg = 0x00;

	uint8_t BMI088regDataA; 				// expect 0x1E
	HAL_StatusTypeDef BMI088statusA; 		//expect HAL_OK
	uint8_t BMI088regDataG; 				// expect 0x0F
	HAL_StatusTypeDef BMI088statusG; 		//expect HAL_OK


//	uint8_t BMI330regData;					// expect 0x23
//	HAL_StatusTypeDef BMI330status;			// expect HAL_OK

	uint8_t BMP388regData; 					// expect 0x50
	HAL_StatusTypeDef BMP388status; 		//expect HAL_OK

	uint8_t LS3MDLregData; 					// expect b00111101
	HAL_StatusTypeDef LS3MDLstatus; 		//expect HAL_OK


//	 BMI088 (ACC)
	BMI088statusA = HAL_I2C_Mem_Read(&hi2c1, (BMI088Aaddress << 1), BMI088DummyReg, I2C_MEMADD_SIZE_8BIT, &BMI088regDataA, 1, 100);
//	 BMI088 (GYRO)
	BMI088statusG = HAL_I2C_Mem_Read(&hi2c1, (BMI088Gaddress << 1), BMI088DummyReg, I2C_MEMADD_SIZE_8BIT, &BMI088regDataG, 1, 100);

	HAL_Delay(10);

//	HAL_StatusTypeDef tempStatus = HAL_I2C_IsDeviceReady(&hi2c1, 0xD0, 3, 100); // extra BMI330 test

	//BMI330
//	BMI330status = HAL_I2C_Mem_Read(&hi2c1, (BMI330address << 1), BMI330DummyReg, I2C_MEMADD_SIZE_8BIT, &BMI330regData, 1, 100);
	// LS3MDL
	LS3MDLstatus = HAL_I2C_Mem_Read(&hi2c1, (LS3MDLaddress << 1), LS3MDLDummyReg, I2C_MEMADD_SIZE_8BIT, &LS3MDLregData, 1, 100);
	// BMP388
	BMP388status = HAL_I2C_Mem_Read(&hi2c1, (BMP388address << 1), BMP388DummyReg, I2C_MEMADD_SIZE_8BIT, &BMP388regData, 1, 100);




	// I2C bus scan
	int tempArr[32];
	for (int i = 0; i < 32; i++) {
		tempArr[i] = 0;
	}
	int arrCount = 0;
	for(uint8_t i = 1; i < 128; i++) {
	    // Shift the 7-bit address left by 1 for the HAL
	    HAL_StatusTypeDef result = HAL_I2C_IsDeviceReady(&hi2c1, (uint16_t)(i << 1), 2, 10);
	    if(result == HAL_OK) {
	    	tempArr[arrCount] = i;
	    	arrCount++;
	    }
	}

	int nothing = 0;


	// 500ms Delay
	//HAL_Delay(500);
}


void Bringup_SPI_Flash(){
	// W25Q64JV

	uint8_t flash_tx[4] = {0x9F, 0x00, 0x00, 0x00};
	uint8_t flash_rx[4] = {0};


	HAL_GPIO_WritePin(FLASH_CS_GPIO_Port, FLASH_CS_Pin, GPIO_PIN_RESET); 	// pull low
	HAL_SPI_TransmitReceive(&hspi2, flash_tx, flash_rx, 4, 100);			// data transfer haha
	HAL_GPIO_WritePin(FLASH_CS_GPIO_Port, FLASH_CS_Pin, GPIO_PIN_SET);		// pull high

	// expect: [1] = 0xEF, [2] = 0x40, [3] 0x17
	// NOTE: I could be wrong about [2] and [3], lowkey guessed because data sheet confuded me :p
	// Also double checck which mode we need to be in when we actually test, might be fine (just leaving for future me)
}

void Bringup_SPI_SD(){
	// 104031
	// Need to 'wake up' the SD Card
	uint8_t dummy = 0xFF;
	uint8_t rx_dump;


	HAL_GPIO_WritePin(SD_CS_GPIO_Port, SD_CS_Pin, GPIO_PIN_SET); // ENSURE THE CS LINE IS HIGH OR ELSE BAD THINGS HAPPEN
	for (int i = 0; i < 80; i++){
		HAL_SPI_TransmitReceive(&hspi3, &dummy, &rx_dump, 1, 10);
	}
	HAL_GPIO_WritePin(SD_CS_GPIO_Port, SD_CS_Pin, GPIO_PIN_RESET);

	uint8_t sd_cmd0[] = {0x40, 0x00, 0x00, 0x00, 0x00, 0x95};
	uint8_t sd_resp = 0xFF;

	HAL_GPIO_WritePin(SD_CS_GPIO_Port, SD_CS_Pin, GPIO_PIN_RESET);
	HAL_SPI_TransmitReceive(&hspi3, sd_cmd0, &rx_dump, 6, 100);

	// keep readnig unril we get a response
	for (int i = 0; i < 10; i++){
		HAL_SPI_Receive(&hspi3, &sd_resp, 1, 100);
		if (sd_resp != 0xFF) break;
	}

	HAL_GPIO_WritePin(SD_CS_GPIO_Port, SD_CS_Pin, GPIO_PIN_SET);

	// expect to get sd_resp == 0x01
}

void Bringup_SPI_DL(){
	// E22-900MM22S
	uint8_t dl_tx = 0xC0;
	uint8_t dl_rx = 0x00;

	// wait for radio to not be busy
	while (HAL_GPIO_ReadPin(TELEM_BUSY_GPIO_Port, TELEM_BUSY_Pin) == GPIO_PIN_SET){}

	HAL_GPIO_WritePin(GPIOC, TELEM_CS_Pin, GPIO_PIN_RESET);
	HAL_SPI_TransmitReceive(&hspi1, &dl_tx, &dl_rx, 1, 100);

	HAL_SPI_Receive(&hspi1, &dl_rx, 1, 100);
	HAL_GPIO_WritePin(GPIOC, TELEM_CS_Pin, GPIO_PIN_SET);

	// expect dl_rx to NOT be 0x00/0xFF
	// idk what to get, but it shouldnt bt that lol. look more into this future me :p
}

void Bringup_UART_GPS(){
	// NEO-M9N-00B

	uint8_t gps_rx[128];
	HAL_StatusTypeDef GPS_Status = HAL_UART_Receive(&huart6, gps_rx, 128, 1000);
	int nothing = 0;
}



// ********************************** INIT HELPERS ************************************************************

static void Init_Buffers(void) {
    CB_Init(&recent_alt);

    LU32_Init(&log_time);

    LFB_Init(&log_pres);
    LFB_Init(&log_temp);
    LFB_Init(&log_alt);

    LFB_Init(&log_ax);
    LFB_Init(&log_ay);
    LFB_Init(&log_az);
    LFB_Init(&log_gx);
    LFB_Init(&log_gy);
    LFB_Init(&log_gz);

    LFB_Init(&log_main_mv);
    LFB_Init(&log_drogue_mv);
    LFB_Init(&log_bat_v);
    LSB_Init(&log_stage);

    LU32_Init(&log_servo);
    LFB_Init(&log_airbrakes_level);
    LFB_Init(&log_filtered_alt);
    LFB_Init(&log_filtered_vel);

    // mag inits
    LFB_Init(&mag_x_buf);
    LFB_Init(&mag_y_buf);
    LFB_Init(&mag_z_buf);
    LFB_Init(&mag_temp_buf);

    // GPS inits
//    LU32_Init(&gps_year);
//    LU32_Init(&gps_month);
//    LU32_Init(&gps_day);
//    LU32_Init(&gps_hour);
//    LU32_Init(&gps_min);
//    LU32_Init(&gps_sec);

    LFB_Init(&gps_longitude);
    LFB_Init(&gps_latitude);

    LFB_Init(&gps_speed);
    LFB_Init(&gps_heading_deg);
    LU32_Init(&log_unix);
}
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

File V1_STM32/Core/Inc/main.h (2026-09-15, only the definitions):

#define TELEM_CS_Pin GPIO_PIN_0
#define TELEM_CS_GPIO_Port GPIOC
#define TELEM_BUSY_Pin GPIO_PIN_1
#define TELEM_BUSY_GPIO_Port GPIOC
#define TXEN_Pin GPIO_PIN_2
#define TXEN_GPIO_Port GPIOC
#define RXEN_Pin GPIO_PIN_3
#define RXEN_GPIO_Port GPIOC
#define Voltage_ADC_Pin GPIO_PIN_0
#define Voltage_ADC_GPIO_Port GPIOA
#define MAIN_DETECT_Pin GPIO_PIN_1
#define MAIN_DETECT_GPIO_Port GPIOA
#define DROGUE_DETECT_Pin GPIO_PIN_2
#define DROGUE_DETECT_GPIO_Port GPIOA
#define Heartbeat_LED_Pin GPIO_PIN_4
#define Heartbeat_LED_GPIO_Port GPIOA
#define SPI_CLK_Pin GPIO_PIN_5
#define SPI_CLK_GPIO_Port GPIOA
#define MISO_Pin GPIO_PIN_6
#define MISO_GPIO_Port GPIOA
#define MOSI_Pin GPIO_PIN_7
#define MOSI_GPIO_Port GPIOA
#define TELEM_CLK_Pin GPIO_PIN_4
#define TELEM_CLK_GPIO_Port GPIOC
#define FLASH_CS_Pin GPIO_PIN_12
#define FLASH_CS_GPIO_Port GPIOB
#define SPI2_CLK_Pin GPIO_PIN_13
#define SPI2_CLK_GPIO_Port GPIOB
#define MISO2_Pin GPIO_PIN_14
#define MISO2_GPIO_Port GPIOB
#define MOSI2_Pin GPIO_PIN_15
#define MOSI2_GPIO_Port GPIOB
#define SD_CS_Pin GPIO_PIN_9
#define SD_CS_GPIO_Port GPIOC
#define GPS_TX_Pin GPIO_PIN_9
#define GPS_TX_GPIO_Port GPIOA
#define GPS_RX_Pin GPIO_PIN_10
#define GPS_RX_GPIO_Port GPIOA
#define USB_D__Pin GPIO_PIN_11
#define USB_D__GPIO_Port GPIOA
#define USB_D_A12_Pin GPIO_PIN_12
#define USB_D_A12_GPIO_Port GPIOA
#define SPI3_CLK_Pin GPIO_PIN_10
#define SPI3_CLK_GPIO_Port GPIOC
#define MISO3_Pin GPIO_PIN_11
#define MISO3_GPIO_Port GPIOC
#define MOSI3_Pin GPIO_PIN_12
#define MOSI3_GPIO_Port GPIOC

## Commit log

2025-09-01 The first official draft of the schematic
    [BMI088.step, BMP388.step, GPS_Telemetry.kicad_sch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]
2025-09-01 Renaming folders
    [GPS_Telemetry.kicad_sch, Memory.kicad_sch, Peripherals.kicad_sch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]
2025-09-01 Re-added kicad/hardware files
    Just doing some organization
    [GPS_Telemetry.kicad_sch, Memory.kicad_sch, Peripherals.kicad_sch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]
2025-09-01 Added all STM32CubeIDE Code
2026-09-15 added the V1 to personal repo from org repo
    [0734120110.stp, 104031-0811.step, 1053091102.stp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]

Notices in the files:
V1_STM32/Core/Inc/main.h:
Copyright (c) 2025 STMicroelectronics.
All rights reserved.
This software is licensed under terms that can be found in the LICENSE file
